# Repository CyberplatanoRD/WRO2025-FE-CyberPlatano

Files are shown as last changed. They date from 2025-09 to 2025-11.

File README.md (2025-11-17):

<h1 align="center">CyberPlátanoRD — WRO</h1>

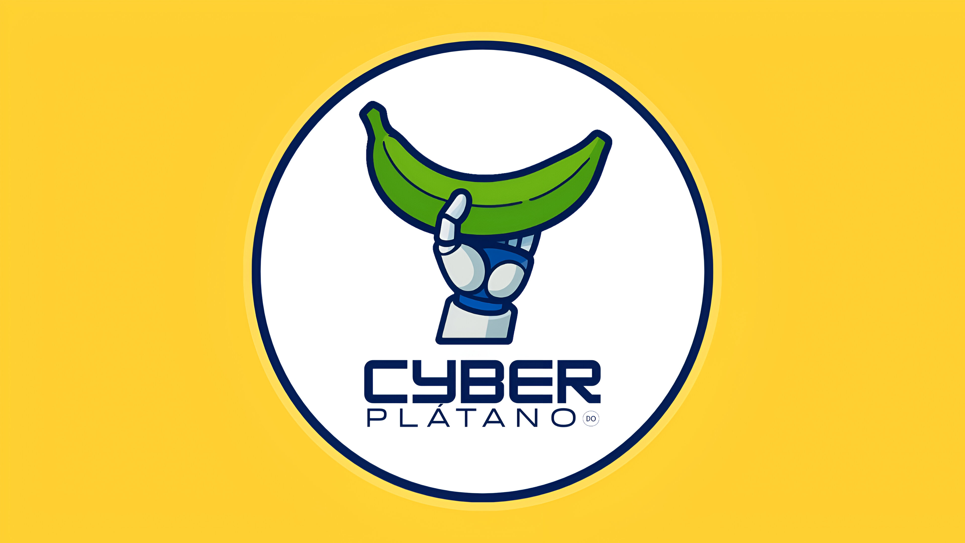
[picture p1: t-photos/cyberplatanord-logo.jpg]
CyberPlátano Logo


> • Pontificia Universidad Católica Madre y Maestra (PUCMM), Dominican Republic • Future Engineers • 2025

---

<p align="center">
  <a href="https://www.youtube.com/@CyberPlatanoWRO">
    
  </a>
  <a href="https://www.instagram.com/pucmm?utm_source=ig_web_button_share_sheet&igsh=ZDNlZDc0MzIxNw==">
    
  </a>
</p>

---

# Engineering Documentation
This repository contains all documentation for the **CyberPlátanoRD** team's robot for the **Future Engineers category - World Robot Olympiad 2025**.  We document the development of our robot, from mechanical and electronic components to programming and simulation.

# Repository Overview

| Folder/File | Description |
|---|---|
| `models` | Files for models used by 3D printers to produce the vehicle elements. |
| `other` | Other essential files. |
| `schemes` | Schematic diagrams of the electromechanical components used in the vehicle and how they connect to each other. |
| `src` | Contains code of control software for all components which were programmed to participate in the competition. |
| `t-photos` | Two photos of the team. |
| `v-photos` | Contains six photos of the vehicle (from every side, from top and bottom). |

# Table of Contents
* [Introduction](#introduction)  
* [About Us](#part-1-about-us)
* [Mobility Management](#part-2-mobility-management)  
* [Power and Sense Management](#part-3-power-and-sense-management)  
* [Obstacle/Open Management](#part-4-obstacleopen-management)

---

# Introduction
This repository documents the journey of Cyberplátano RD, a team representing the Dominican Republic in the World Robot Olympiad (WRO) 2025 – Future Engineers Category, to be held in **Singapore**.

**Our goal** is to design, build, and program an autonomous robot car capable of completing the competition challenges: the Open Challenge and the Obstacle Challenge. The project integrates mechanical design, electronics, and software, combining skills from 3D printing, circuit design, and programming in C++ and Python.

By sharing our process through this repository, **we aim** to provide transparency in our work, create a detailed record of our engineering decisions, and contribute to the global robotics community. Every step, from materials and schematics to testing and results, is documented here.

## Documentation Video

---

# Part 1: About Us

## Our Team 
We are CyberPlátano, representing the Caribbean, Dominican Republic. Part of the PUCMM Robotics Club and guided by our mentor Álvaro Zapata, we are a group of young future engineers. Our club first competed in WRO 2023 in Panamá, and this year we continue our journey, bringing innovation, teamwork, and passion to the international stage in Singapore.

Our team consists of three Mechatronics Engineering students from  "Pontificia Universidad Católica Madre y Maestra (PUCMM)" currently in their third semester. We met during our studies and decided to collaborate as teammates, driven by our shared interest in robotics and innovation. Throughout our academic journey, we have gained valuable experience from our university projects and from the guidance of our professors and peers. This collaboration and learning process have led us to participate together on this international stage.

---

##  Team Members

#### 1. Ivan Saint-Hilaire - Software / Mechanical Eng. ####
| Photo | Role |
|---|---|
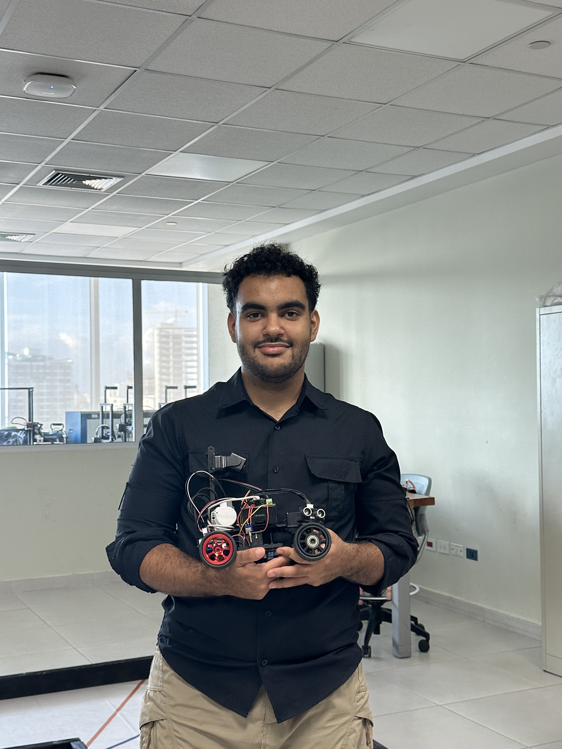
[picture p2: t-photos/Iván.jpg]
|   | Iván is responsible for designing and optimizing the mechanical components of the robot while also developing and integrating the software that controls its functions. His expertise ensures that the robot operates efficiently, accurately, and reliably, bridging the gap between hardware and software.|

#### 2. Brittany Martinez - Team Coordinator and Document Designer  ####
| Photo | Role |
|---|---|
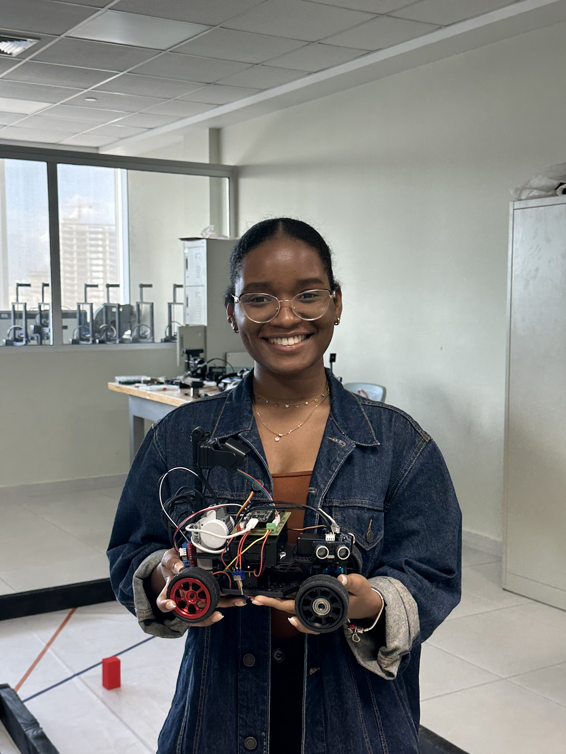
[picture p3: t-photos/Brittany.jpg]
|  | Brittany is responsible for documentation. She has skills in electronics and programming, which allow her to keep the team’s processes well organized. She also ensures that all procedures and systems the team works on are carried out accurately and correctly, maintaining a clear workflow.|

#### 3. Maria Liz Ramos  - Electronics Eng. ####
| Photo | Role |
|---|---|
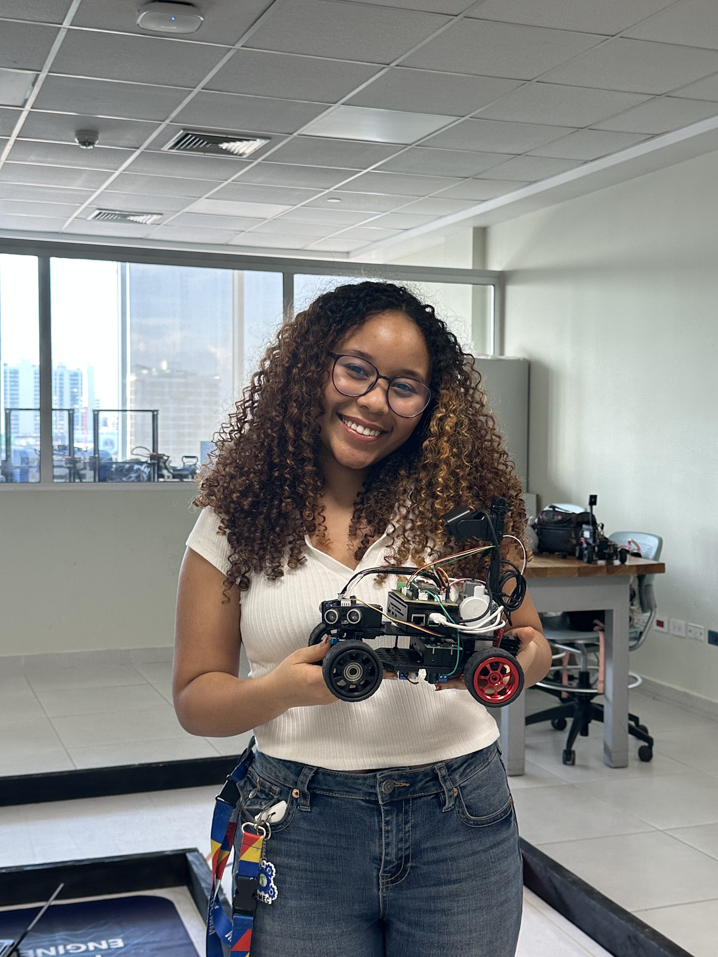
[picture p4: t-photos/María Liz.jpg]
|   | María is responsible for designing, implementing, and maintaining the robot’s electronic systems, ensuring all sensors, circuits, and components function accurately and reliably for optimal performance in the competition.|

#### Alvaro Zapata  - Coach ####
| Photo | Role |
|---|---|
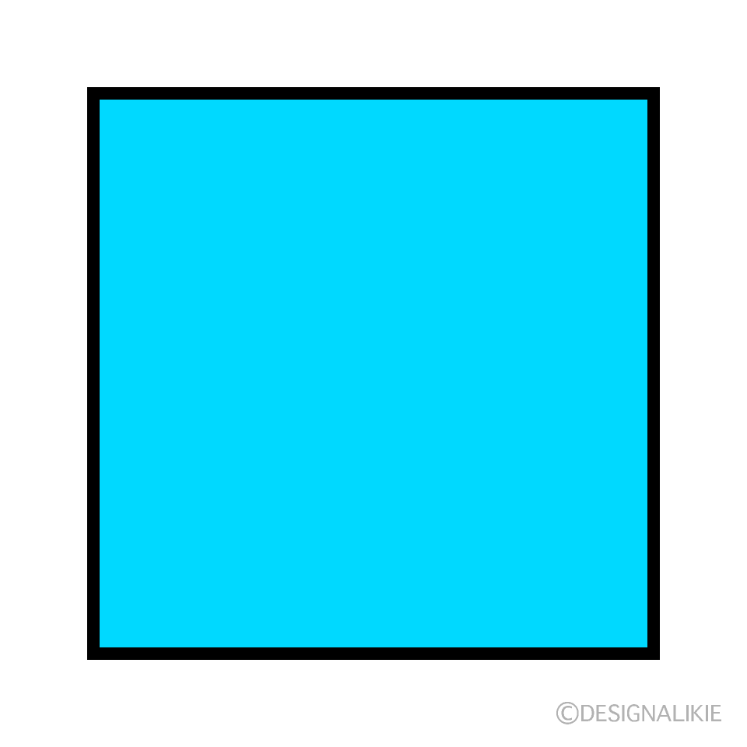
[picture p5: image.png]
|  | Alvaro is a Mechatronics Engineer, he mentors the team, providing technical guidance, strategic advice, and support to ensure the robot performs efficiently and the team works effectively.|

---

##  Work Schedule

This Gantt chart shows the planned timeline for the development of the WRO Future Engineers 2025 robot. It summarizes the main project phases—including design, mechanical build, electronics integration, software development, testing, and final optimization providing a clear view of deadlines and progress for each task.

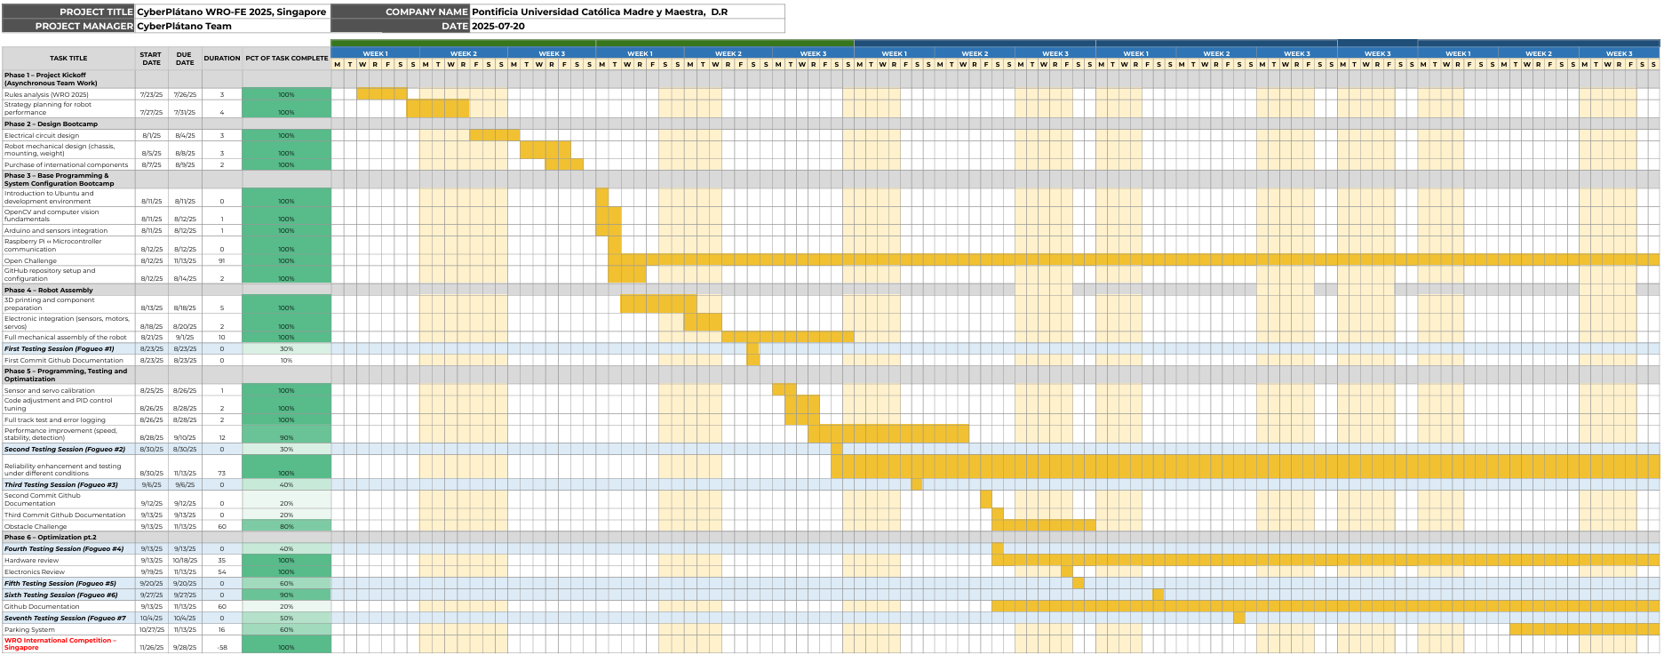
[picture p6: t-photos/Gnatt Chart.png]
Gantt Chart


---

# Part 2: Mobility Management
---
## Robot's Chassis 
Our robot’s chassis has been completely designed and developed from scratch, using Fusion 360 and 3D-printed in black PLA. The design philosophy is centered around modularity, balance, and accessibility, allowing easy modifications, component replacements, and upgrades throughout the development cycle.

We structured our chassis with three essential parts, each designed to provide both strength and modularity to the overall frame:

- **Main Base:** the central foundation that supports the main driving axis, ensuring precise alignment, rigidity, and stability for the entire chassis. 

- **Back Support**: provides mechanical rigidity and structural stability when handling torque or minor impacts. It connects the rear section of the chassis to the upper base and securely holds the drivetrain motor, maintaining alignment under load.

- **Upper Base:** holds the Raspberry Pi 5 and ESP32-CAM circuit, securing them in a stable and elevated position. It also locks the soldered board and supports the ultrasonic sensor mount, ensuring optimal positioning and cable organization.

- **Standoff:** connects the upper base and the main base, maintaining structural spacing and alignment between both layers. It provides rigidity and prevents vibrations from transferring between mechanical and electronic components.

Each element interlocks seamlessly, resulting in a lightweight yet durable frame. Cable management channels were integrated into the design to maintain a clean wiring layout and prevent interference with moving parts. The modular assembly also allows future versions to incorporate sensor mounts or additional mechanical features without redesigning the entire frame.

During the design process, special attention was given to:

- **Weight distribution**, ensuring the center of gravity remains low and centered.

- **Thermal management**, by maintaining airflow under the electronics.

- **Maintenance accessibility**, allowing any component to be removed within minutes.

All the 3D printable models can be found [here](#models).

---
## Robot's Steering System 
---
<p align="justify">
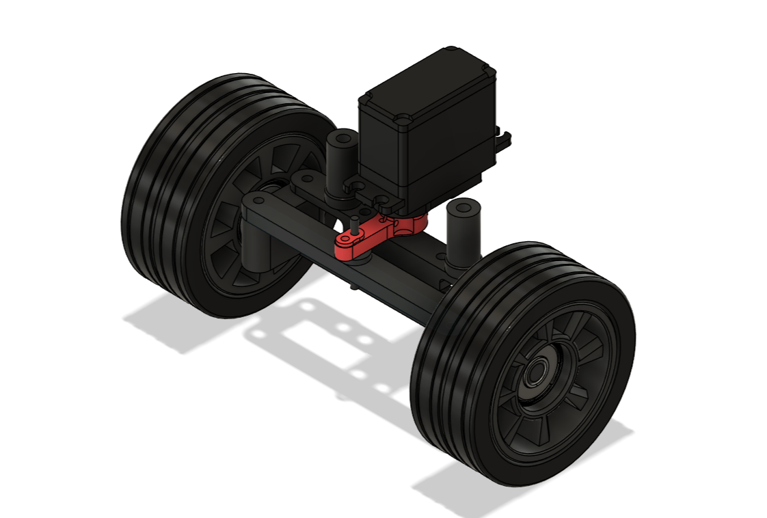
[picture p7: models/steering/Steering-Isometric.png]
  
  Our robot's steering system was designed to provide precise and stable control of forward movement, ensuring the necessary maneuverability across different competition scenarios. We drew inspiration from <em>Ackermann steering system</em>, a configuration that allows a vehicle's front wheels to turn at different angles, enabling them to trace arcs with different radii during a turn. This prevents slipping and improves stability. The entire steering mechanism was developed and modeled in Fusion 360, prioritizing structural integration, modularity, and ease of maintenance. 
</p>

[Click here to view 3D model!](models/steering/steeringSTL.stl)

---
### Steering System Design
---
We took inspiration from a steering design previously developed by our coach, as well as several robotic systems found online. Building upon these references, we carried out an iterative improvement process to address issues related to tolerance, rigidity, and assembly accuracy inherent to 3D-printed components.

In our first prototype, the holes were designed with excessive tolerance, causing loose fits that affected the wheel hubs’ precision and stability. This led to misalignment and unwanted wheel play.

Throughout development, we produced **three main iterations** of the wheel hub design:

1. **First version:** It relied heavily on tight fitting between printed parts, making the design highly sensitive to printer tolerance variations. The wheels were not firmly secured and tended to detach during movement.
2. **Second version:** The fit dependency was reduced, and performance slightly improved; however, the vehicle’s axle and the hub’s axle were designed as separated parts within the same assembly. This made the system mechanically complex and caused lateral play in the wheels. Under repeated stress, the structure eventually fractured.
3. **Final version:** We decided to fully replace the tire rim with a 3D-printed one, which simplified the wheel-to-chassis connection and increased structural rigidity. We also incorporated design inspiration from other teams and opted to use **two 608ZZ bearings** instead of four, which effectively reduced lateral movement without sacrificing rotational smoothness.

Our final steering design combines rigidity, modularity, and precise control while maintaining the simplicity required for quick maintenance and adjustments during the competition.

The steering system consists of the following components:

| No. | Component | Description | Material / Specs |
|:---:|:---|:---|:---|
| 1 | **Under Column** | Lower support structure connecting wheel hubs and servo assembly. | PLA (3D printed), infill 20%, 0.2 mm layer height |
| 2 | **Upper Column** | Upper link supporting the servo and steering mechanism. | PLA, 20% infill, 0.2 mm |
| 3 | **StandOff 1 / 2** | Connect upper and lower columns maintaining alignment. | PLA, 20% infill |
| 4 | **Servo Hitec HS-485B** | Provides steering torque and precision control. | Torque 4.8 kg·cm 6V, 0.16 s/60° |
| 5 | **Bearings 608ZZ** | Enable smooth wheel rotation with minimal friction. | Ø22 mm × 7 mm |
| 6 | **Horn / Servo Arm** | Transmits motion from servo to steering link. | ABS (purchased from Amazon) |
| 7 | **Steering Link (Tie Rod)** | Connects both wheel hubs ensuring synchronized turning. | PLA, 30% infill |
| 8 | **Wheel Hubs** | Support the wheels and allow rotation through bearings. | PLA, 20% infill |
| 9 | **Steering Arm** | Intermediate printed lever that connects the servo horn to the steering link, transmitting motion. | PLA, 20% infill |

###  Steering Subassembly
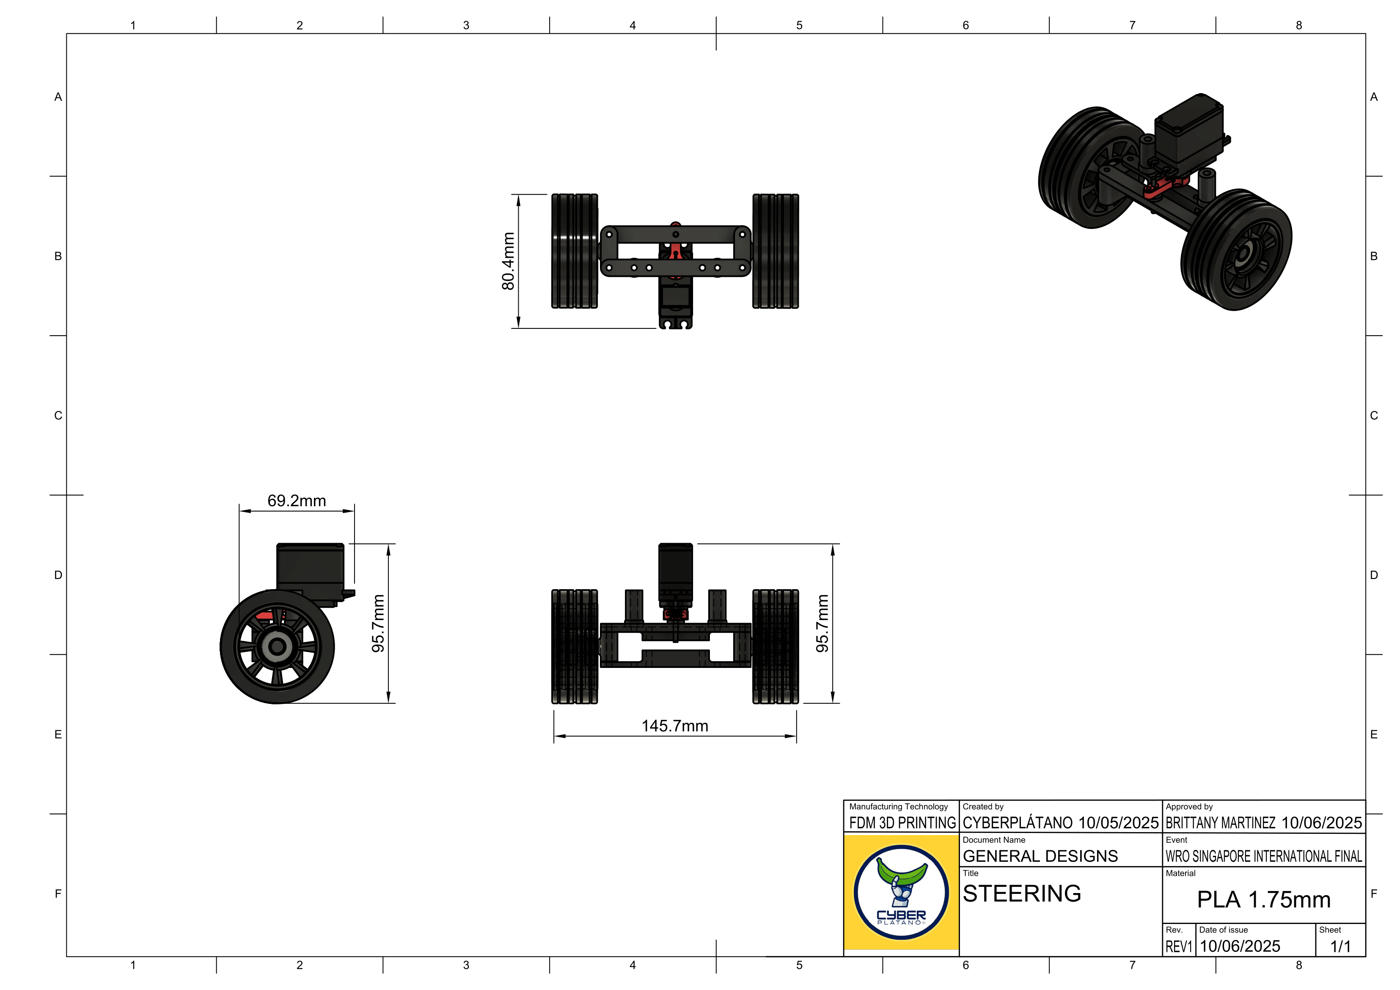
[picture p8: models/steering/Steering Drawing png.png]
Steering Drawing


### 1. Under and Upper Columns 
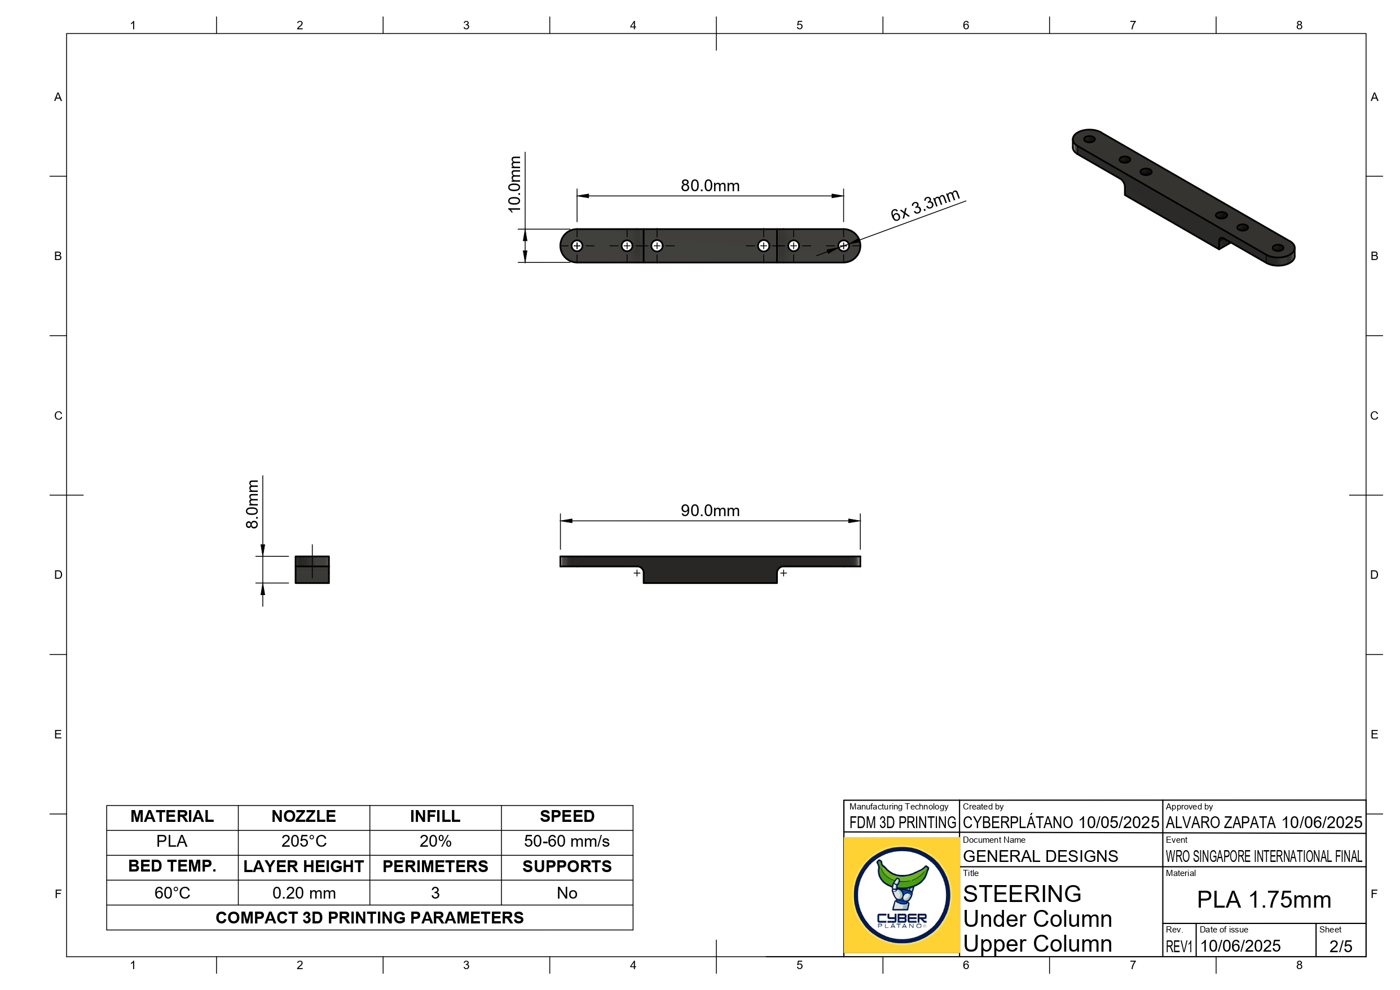
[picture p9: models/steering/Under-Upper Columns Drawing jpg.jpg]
Under-Upper Columns Drawing


### 2. Stands Off 
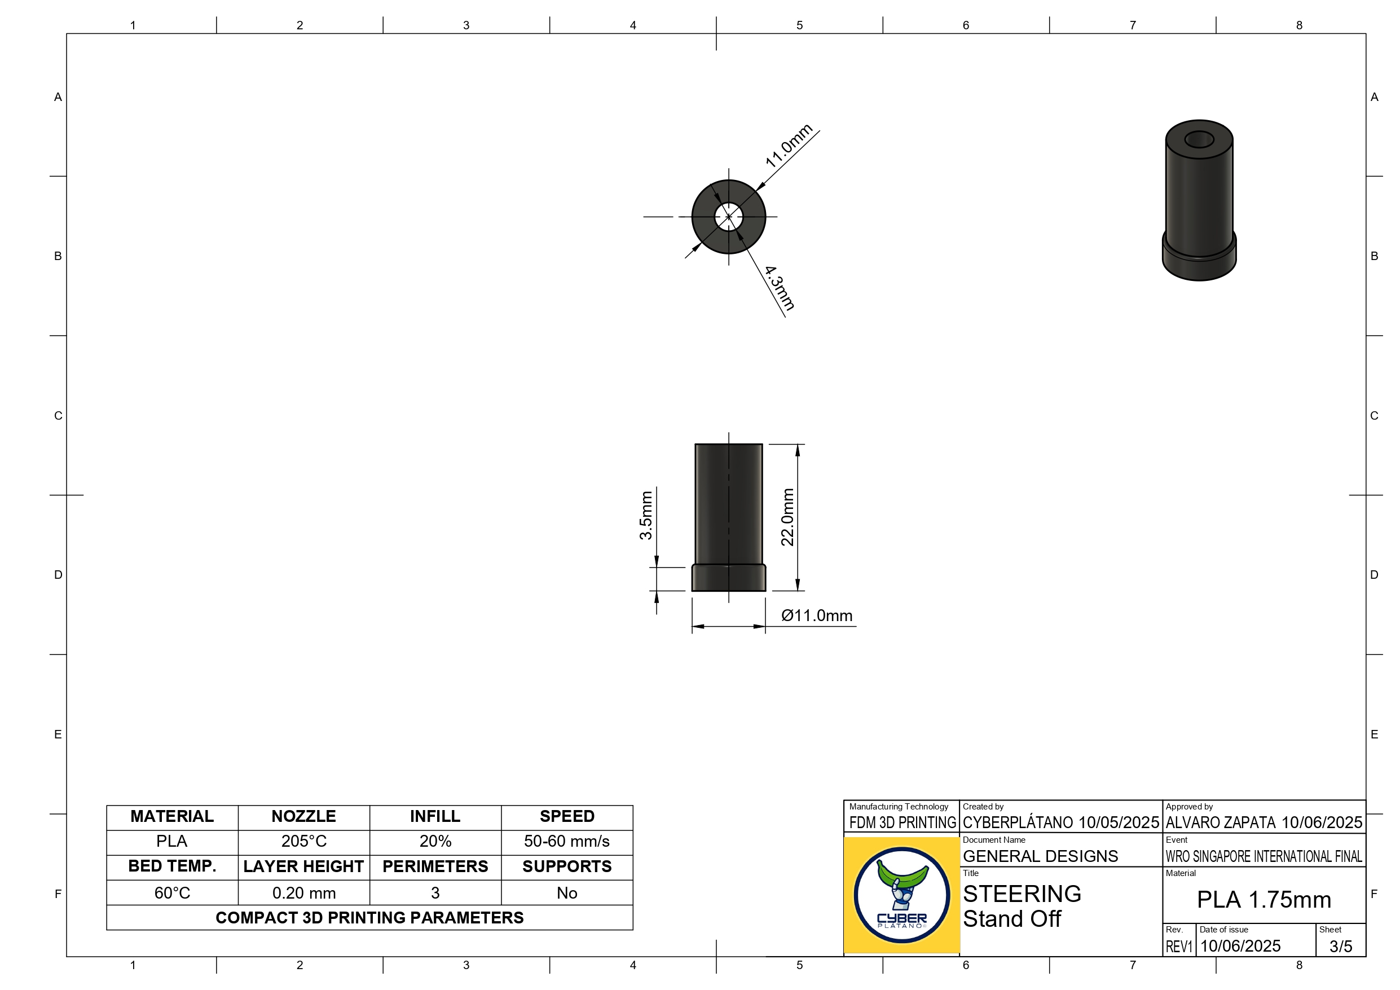
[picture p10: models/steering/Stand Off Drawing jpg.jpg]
Stand Off Drawing


### 3. Steering Arm
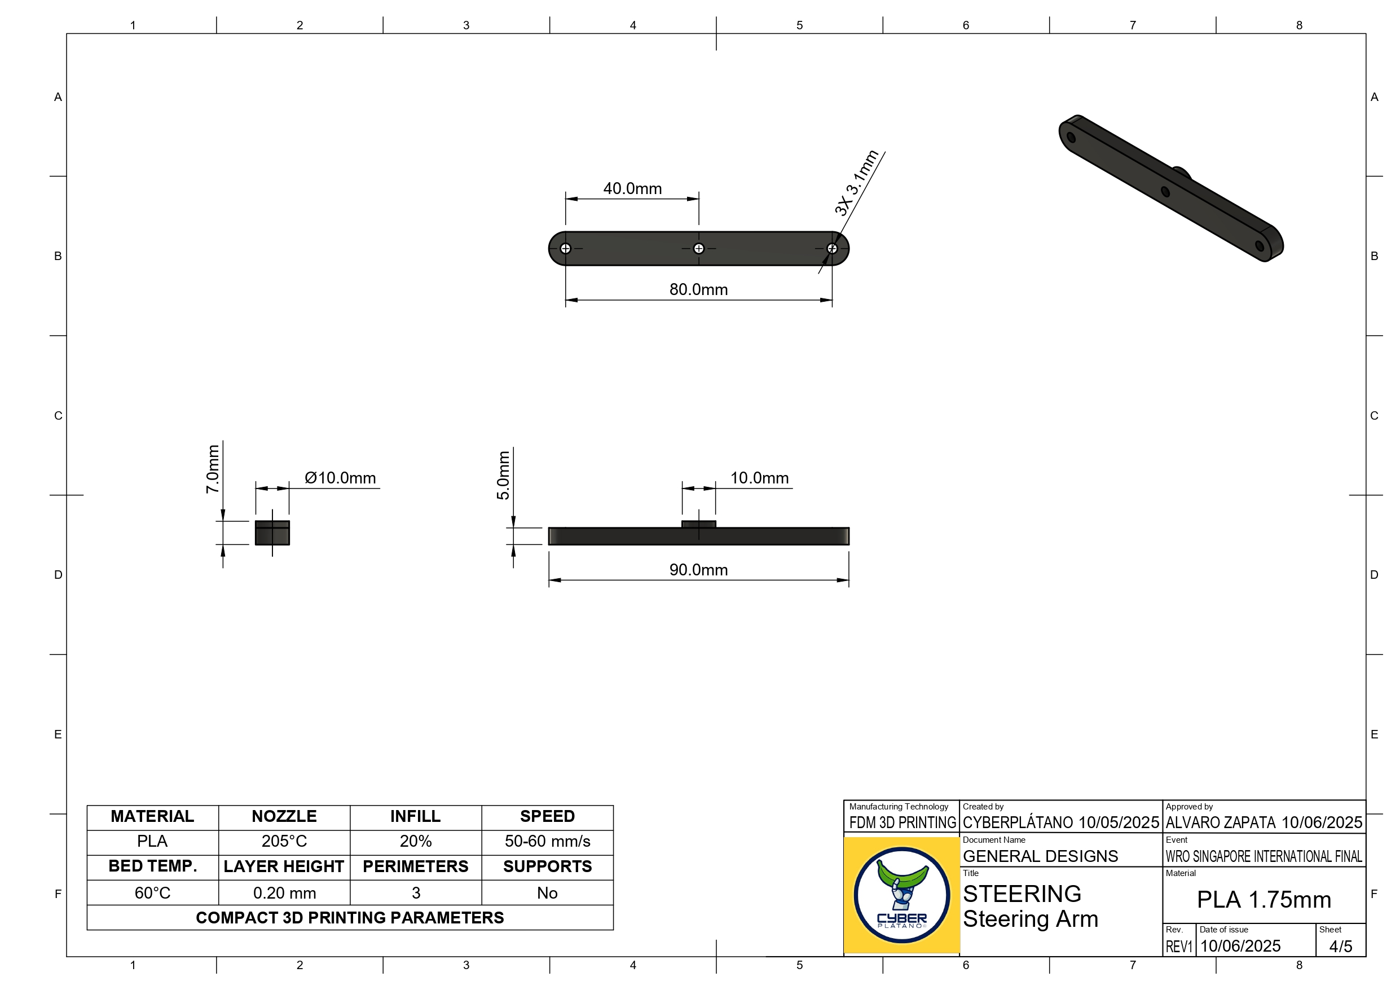
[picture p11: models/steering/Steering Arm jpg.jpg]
Steering Arm Drawing


### 4. Frontal Rims 
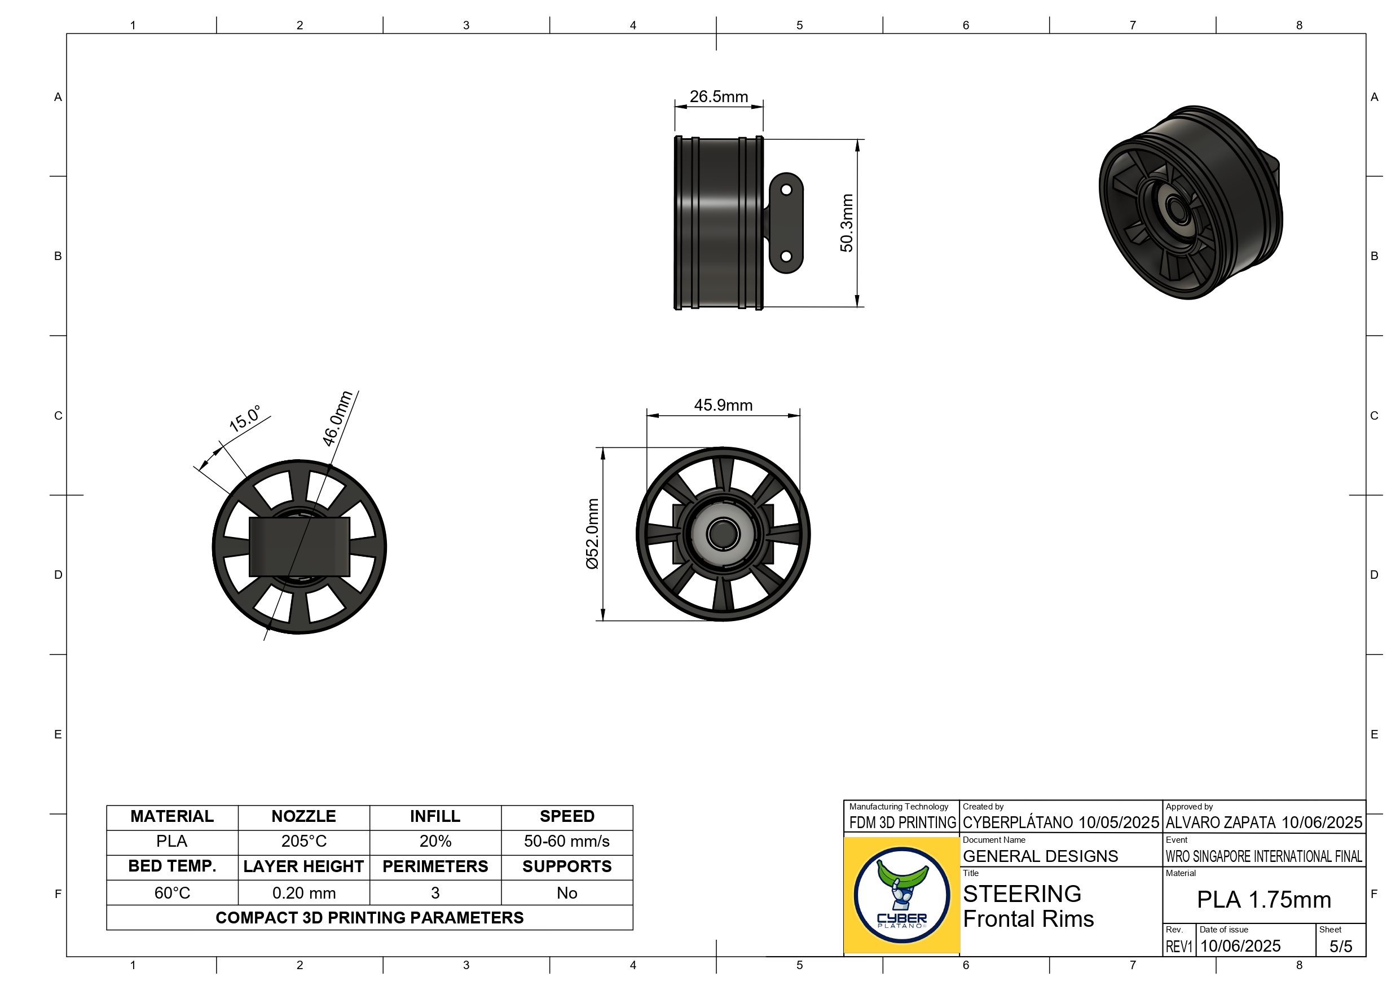
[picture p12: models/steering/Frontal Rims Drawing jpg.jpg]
Frontal Rims Drawing


---
### Our Key Steering Component: HS-485HB Servo Motor
---
Our primary steering component—the Hitec HS-485HB servo motor was initially chosen because it was the unit available to us at the time, extensive testing quickly proved it to be a reliable and well-suited choice for our steering system. Over more than three months of continuous use, the HS-485HB has demonstrated excellent consistency, durability, and torque stability, even under repetitive steering cycles and high-load maneuvers typical of competition environments. Its Karbonite gear train, known for increased wear resistance, has provided smooth motion transfer without backlash, and its response time has been fast enough to ensure accurate directional control on the field. What began as a practical selection evolved into a confident engineering decision, reinforced by the servo’s performance, structural robustness, and zero failure rate throughout our development process.

<table>
  <tr>
    <td align="center" width="450">
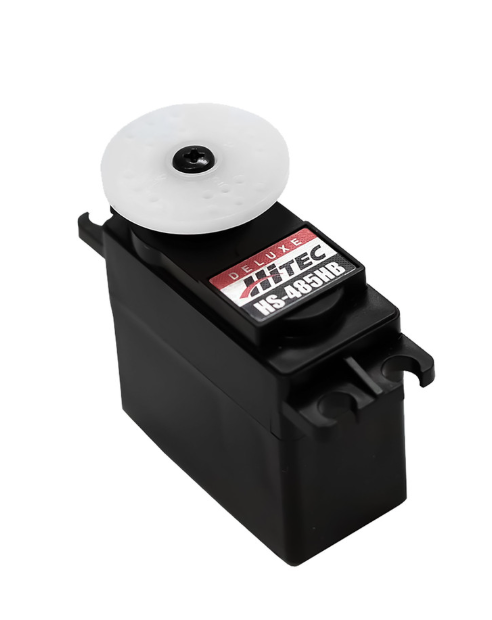
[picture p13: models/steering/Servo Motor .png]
      
      <br>
      <b>HS-485HB Servo Motor</b>
    </td>
    <td>

| **Parameter** | **Specification** |
|---|---|
| Servo type | Standard, limited rotation (±60°) |
| Operating voltage | 4.8 V – 6.0 V |
| Torque | 4.8 kg·cm @ 4.8 V / 6.0 kg·cm @ 6.0 V |
| Speed | 0.22 s/60° @ 4.8 V / 0.18 s/60° @ 6.0 V |
| Gear material | Karbonite (high wear resistance) |
| Bearing type | Dual ball bearings |
| Dimensions | 39.8 × 19.8 × 38.0 mm |
| Weight | 45 g |
| Output spline type | 24T (Hitec) |
| PWM signal range | 900–2100 µs (typical) |
| Operating current | ~160–200 mA (under moderate load) |
| Stall current | Up to ~1.2 A (approx., depending on load) |
| Case material | Reinforced plastic |
| Connector | Futaba-type (3-pin) |

  </td>
  </tr>
</table>

---
### Bill of Materials (BOM)
---
| **Component** | **Description** | **Qty** | **Unit Price (USD)** |
|---|---|---|---|
| [Raspberry Pi 5](https://a.co/d/0I2nEqT) | Main computer used for high-level processing and running computer vision algorithms. | 1 | $98.00 |
| [ESP32](https://a.co/d/hiSPSgg) | Microcontroller responsible for real-time control of motors and sensors, communicating with the main processor. | 1 | $10.00 |
| [Motor Lego NXT](https://ebay.us/m/x9oEc6) | DC motor with encoder used for driving the wheels, providing precise speed and position feedback. | 1 | $7.00 |
| [NXT Lego Cable](https://ebay.us/m/tDWV4P) | Connects NXT motors and sensors to the control electronics. | 1 | $1.50 |
| [65mm Wheels](https://es.aliexpress.com/item/1005008744796805.html) | Provide traction and mobility to the robot. | 4 | $5.00 |
| [H-Bridge (L298N)](https://a.co/d/6sx6nvQ) | Motor driver that allows bidirectional control of the DC motors, enabling forward and backward movement. | 1 | $2.50 |
| [Creality Nebula Camera](https://a.co/d/1rddk0F) | Captures real-time video feed for visual processing, compatible with Raspberry Pi and AI-based image recognition. | 1 | $29.00 |
| [Servo Motor HS-485HB](https://a.co/d/8K9dx9H) | Controls steering (front axle movement) or small actuations requiring angular precision. | 1 | $19.00 |
| [Servo Motor Horn](https://a.co/d/hKtnZTU) | Mechanical arm attachment for the servo motor, transmits angular motion to the steering mechanism. | 1 | $9.00 |
| [Ultrasonic Sensor (HC-SR04)](https://a.co/d/gGVXDkd) | Measures distance to nearby objects for obstacle detection and wall avoidance. | 3 | $4.50 each |
| [MPU9250](https://a.co/d/abgbahF) | Inertial Measurement Unit (IMU) that provides accelerometer, gyroscope, and magnetometer data for orientation and navigation. | 1 | $17.00 |
| [Switch SPST 6A](https://a.co/d/7QAXuRy) | Main power switch to safely turn the robot ON/OFF. | 1 | $0.50 |
| [Push Button](https://a.co/d/fHT8FXe) | Used as a start/stop input for robot operation. | 1 | $1.50 |
| Lego Motor Shaft | Mechanical part that transfers torque from the motor to the wheels/axle. | 1 | $0.10 |
| [Dual Power Supply (DC-DC Boost)](https://es.aliexpress.com/item/1005007460824944.html) | Dual-output voltage regulator that steps up DC input to supply stable voltage levels to different modules. | 1 | $4.97 |
| [UPS Power Supply/Converter](https://es.aliexpress.com/item/1005005195434497.html) | Uninterruptible power supply module that maintains power delivery during voltage drops or disconnections. | 1 | $1.40 |
| [Bearings 608zz](https://a.co/d/b21FcTB) | Ball bearings used to reduce friction and support smooth wheel or axle rotation. | 2 | $0.20 |
| [Buck Converter XL4015](https://a.co/d/3TFsw20) | Step-down voltage regulator providing a stable 5V or 12V output for the control electronics. | 1 | $0.98 |
| [PLA Filament (Polylactic Acid)](https://a.co/d/bzdKSjG) | Material used for 3D printing the chassis and custom parts of the robot due to its light weight and ease of printing. | 1 | $25.00 |
| **Total Estimated Cost** |  |  | **$239.85** |

# Part 3: Power and Sense Management
---
This report presents the design, development, and integration of the electrical system implemented in the autonomous vehicle built for the WRO Future Engineers 2025 competition.

The main objective of the electrical subsystem was to provide a **reliable architecture for the robot’s power supply, sensing, processing, and actuation, ensuring stability, safety, and compatibility** with the challenge requirements, where the track changes dynamically in each round.

The system is based on an **ESP32 microcontroller**, responsible for managing the **ultrasonic sensors**, the **Creality Nebula Camera** for color recognition, and motor control. Power is supplied using 18650 lithium batteries, step-down regulators, a dual power source, and a custom PCB design to ensure proper power distribution and minimize interference caused by the motors.

Throughout the development process, tests were conducted on continuity, current consumption, sensor calibration, and digital communication validation. The main challenges included stabilizing the Raspberry Pi 5 power supply, mitigating electrical noise from the motors, dealing with the limited number of available pins, and unstable color readings, which led to several iterations in wiring, pin assignment, and signal filtering.

The results demonstrate that the electrical system met the minimum requirements for functional operation, enabling successful integration with the mechanical and control systems. Finally, potential improvements were identified, such as the implementation of encoders, sensor filtering optimization, and PCB refinement for future versions.

## Schematics
> Diagrams and PCB Layout files available in [schemes/](schemes/).

### Diagram - Preview
[View full PDF](./schemes/WRO_Generalsquematic.pdf)

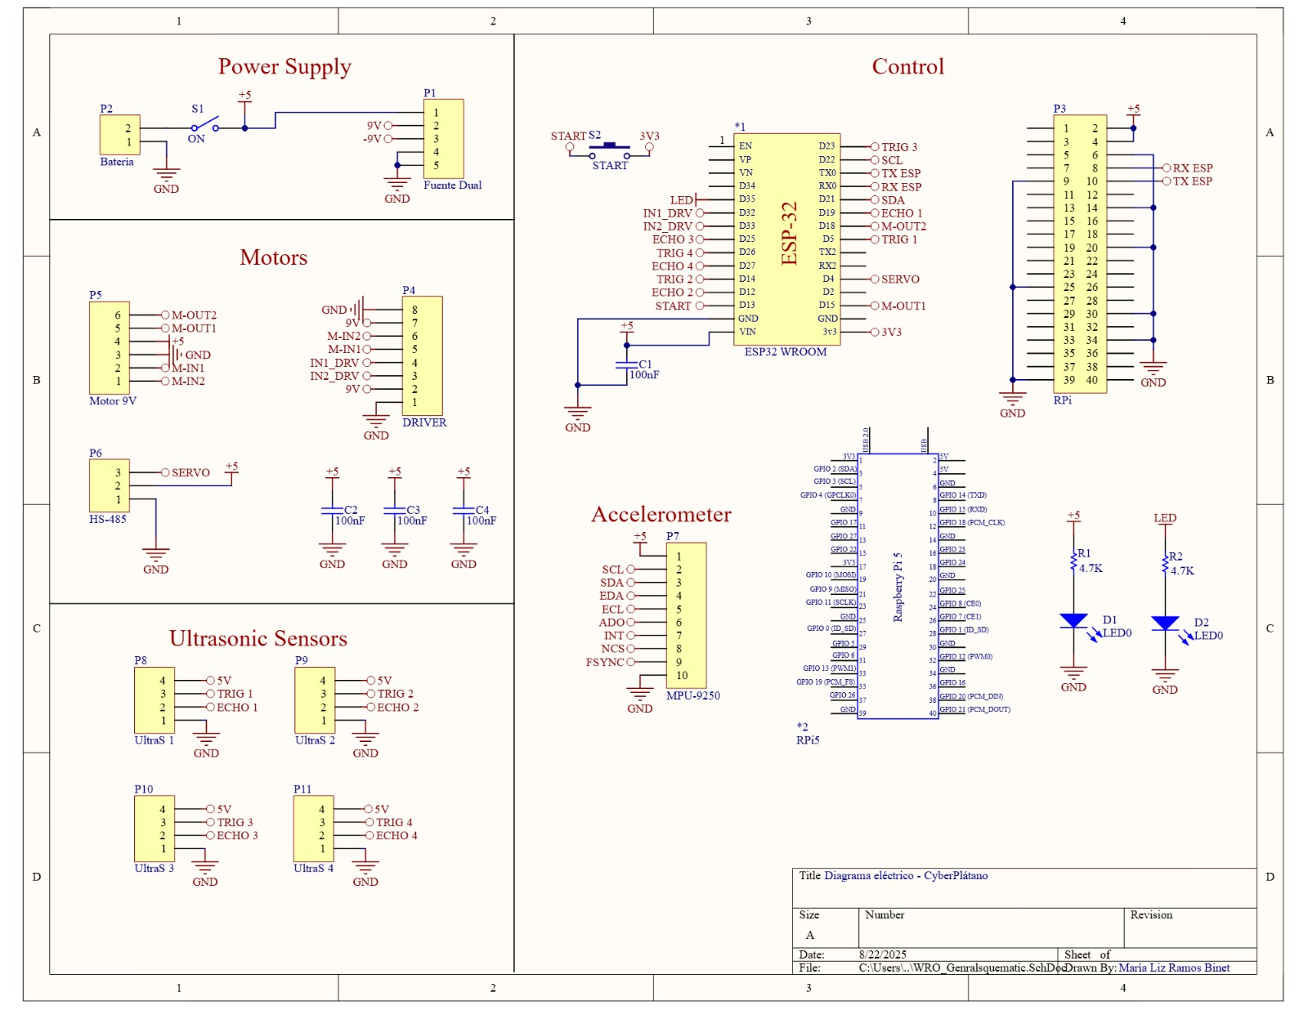
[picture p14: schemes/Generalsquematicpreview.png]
Schematic Preview


### PCB layout - Preview
[View full PCB Layout](./schemes/WRO_Generalpcblayout.pdf)

# Part 4: Obstacle/Open Management
> CPP and Python codes files available in [src/](src/).

### Open challenge - Preview

Below is a short preview of the control logic used in our Open Challenge robot.  

The full version is available here  [`src/open_challengev2.ino`](./src/open_challengev2.ino)

```cpp
#include <Wire.h>
#include <MPU9250_asukiaaa.h>
#include <ESP32Servo.h>

MPU9250_asukiaaa mySensor;
Servo servoMotor;

// Basic yaw control variables
float yaw = 0.0;
float gyroZ_offset = 0.0;

void setup() {
  Serial.begin(115200);
  Wire.begin();
  mySensor.setWire(&Wire);
  mySensor.beginGyro();
  servoMotor.attach(18);
}

void loop() {
  mySensor.gyroUpdate();
  yaw += (mySensor.gyroZ() - gyroZ_offset) * 0.01;
  servoMotor.write(map((int)yaw % 360, 0, 360, 50, 130));
}

// ...rest of preview code...

```
---

### Obstacle challenge
---

## Testing
The **"fogueos"** are an internal dynamic organized by the teams from PUCMM (Pontificia Universidad Católica Madre y Maestra), where participants from WRO Dominican Republic take part in friendly mini competitions.

The main goal is to test the robots under competition-like conditions, evaluate team performance, and share knowledge and improvements among teams.

Throughout this process, our team participated in several fogueos to enhance the robot’s precision, stability, and overall performance:

### "1st fogueo"
### "2nd fogueo"
### "3rd fogueo"
### "4th fogueo"
### "5th fogueo"
### "6th fogueo"
### "7th fogueo"
---

## Instructions

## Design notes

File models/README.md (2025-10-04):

# Models

This folder contains the 3D models and related files for the CyberplátanoRD robot project for WRO 2025.

## Files included

- 3D CAD files (e.g., `.stl`, `.step`, `.obj`) for robot components.
- Assembly models showing how the robot parts fit together.
- Any additional reference files used for simulation or design.

## Notes

- Models can be opened with software such as:
  - Fusion 360
  - SolidWorks
  - Blender
  - Webots (for simulation)
- Make sure to check file versions; some parts may have multiple iterations.

## How to use 

1. Open the CAD or simulation software of your choice.
2. Import the 3D files from this folder.
3. Follow the assembly references to reconstruct the robot.
4. Use the models in simulations, presentations, or for 3D printing.

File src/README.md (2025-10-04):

# Source Code

This folder contains the source code for the Open Challenge and Obstacle Challenge robot of the CyberPlátanoRD team for WRO 2025.

## Files included

- `open_challengev2.ino` – Main Arduino sketch for the robot.
  - Handles motor control, yaw adjustment, servo steering, and ultrasonic sensors.
  - Implements corner detection logic and motor stop after a number of rotations.

## Notes

- The code is designed for ESP32 with MPU9250 sensor, servo motor, L298N driver, and ultrasonic sensors.
- Calibration of the gyroscope is performed in the `setup()` function.
- The main loop integrates sensor readings and controls motors and servo based on yaw and ultrasonic distances.

## How to use

1. Open the `.ino` file in Arduino IDE or VS Code with PlatformIO.
2. Make sure all required libraries are installed:
   - `MPU9250_asukiaaa`
   - `ESP32Servo`
3. Connect the ESP32 and upload the sketch.
4. Adjust pins if needed for your hardware setup.

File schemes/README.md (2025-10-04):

# Schematics

This folder contains the schematics and layout files for our WRO 2025 robot project.

## Files included

- `WRO_Generalsquematic.pdf` – Full schematic of the robot, showing all circuits and connections.
- `Generalsquematicpreview.png` – Preview image of the schematic for quick reference.

## Notes

- The PDF file contains detailed information on motor control, sensors, Raspberry Pi 5 and the ESP32-CAM connections.
- The preview image is used in the main README for a quick visual reference.

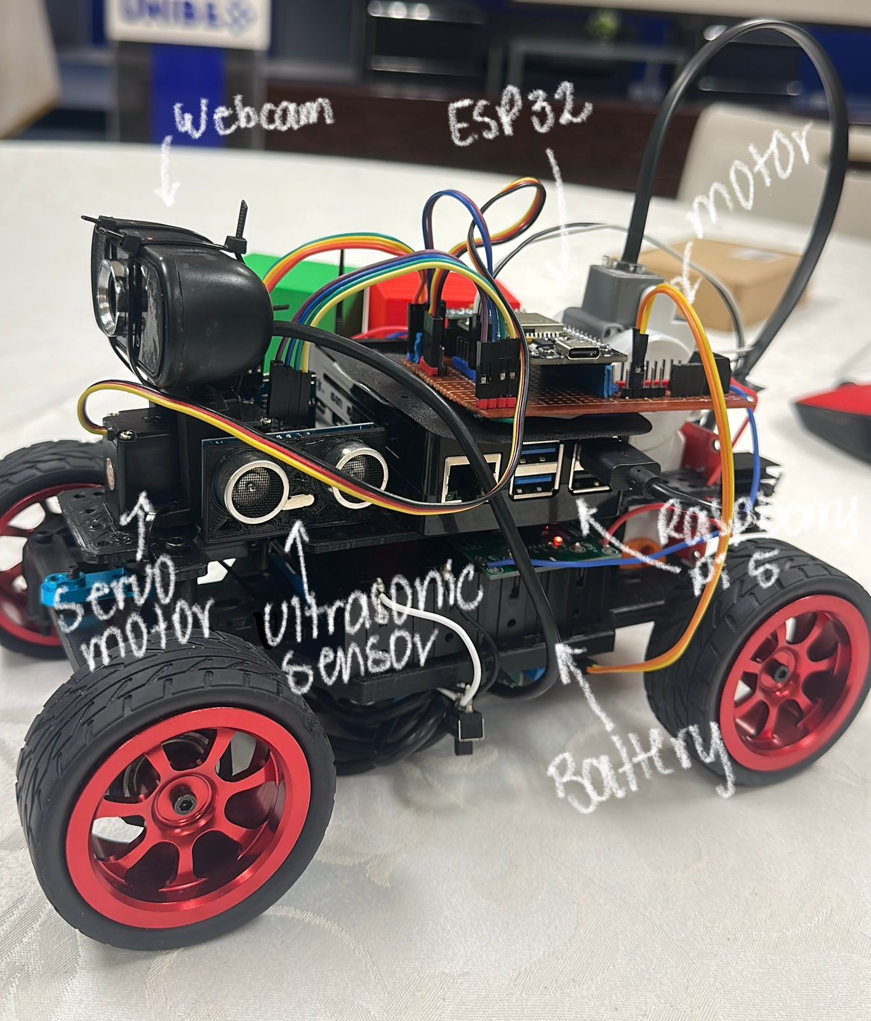
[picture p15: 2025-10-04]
other/Isometric.jpeg

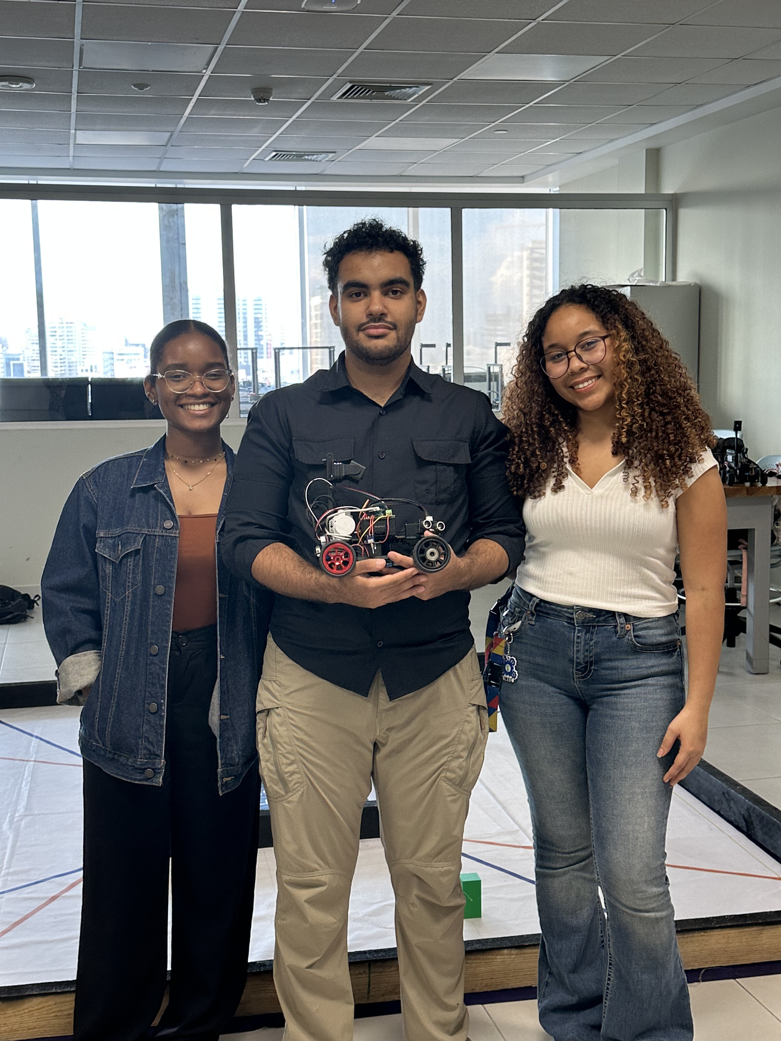
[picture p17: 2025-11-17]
t-photos/Team.jpg

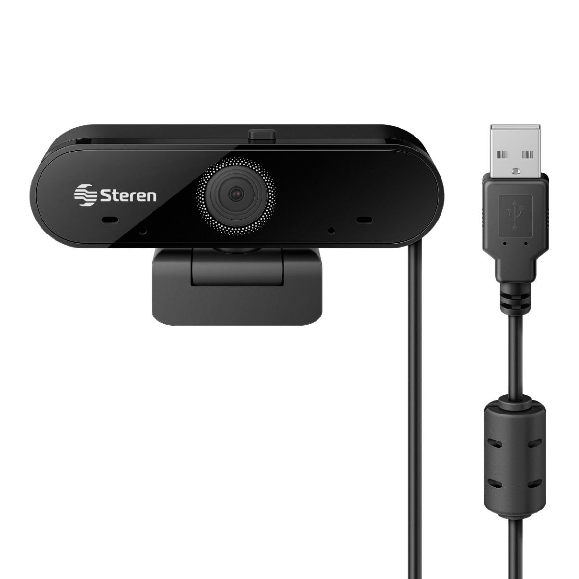
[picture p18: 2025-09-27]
other/webcam.png

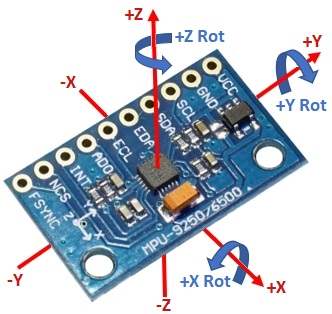
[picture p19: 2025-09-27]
other/IMU.png

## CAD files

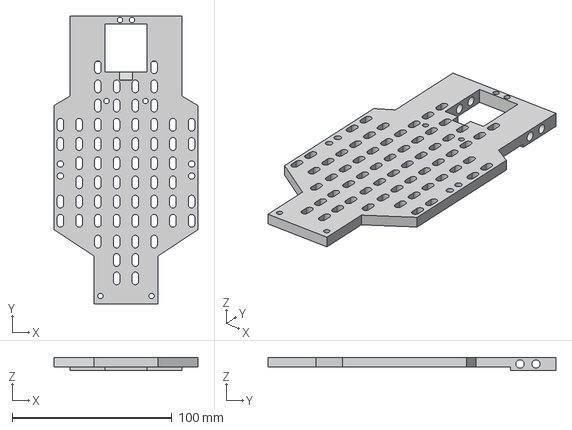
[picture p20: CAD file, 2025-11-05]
models/chassis/main_base/mainBase.step
90.0 x 180.0 x 8.00 mm

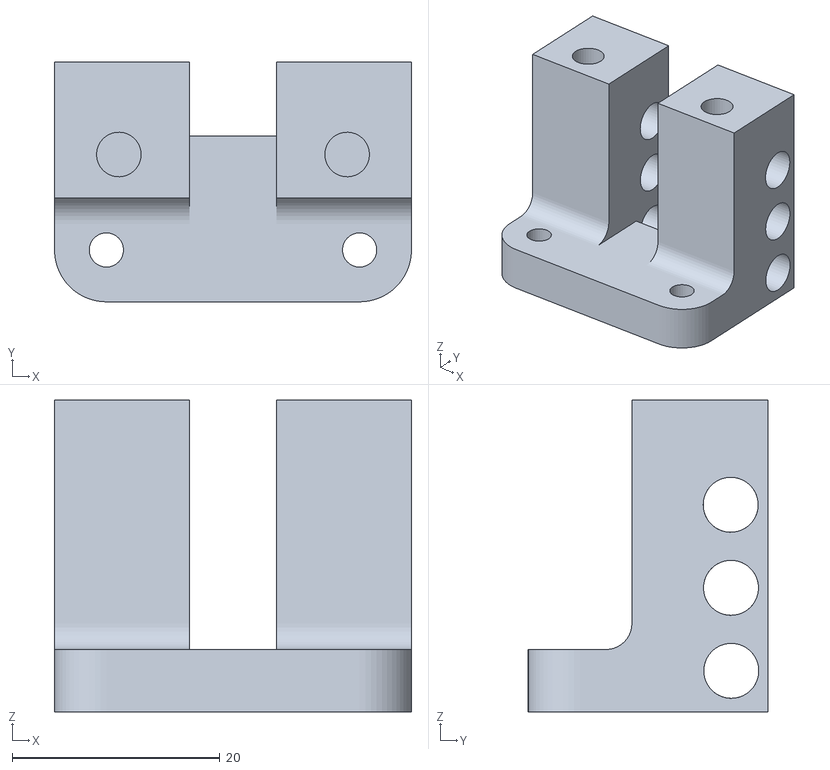
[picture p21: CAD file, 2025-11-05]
models/chassis/back_support/backSupportSTL.stl
34.4 x 23.1 x 30.0

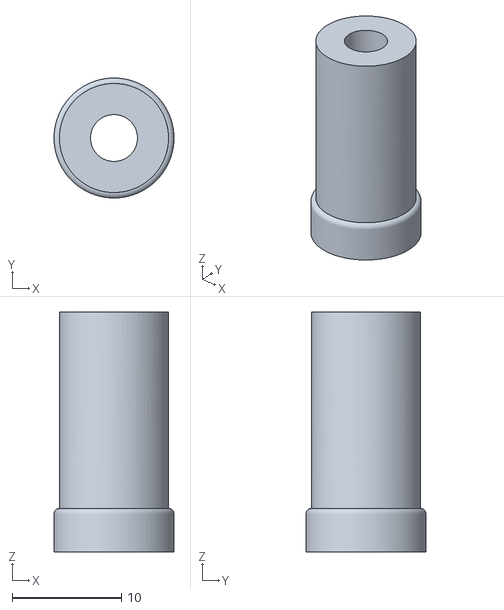
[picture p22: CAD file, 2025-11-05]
models/chassis/stand_off/standOffSTL.stl
11.0 x 11.0 x 22.0

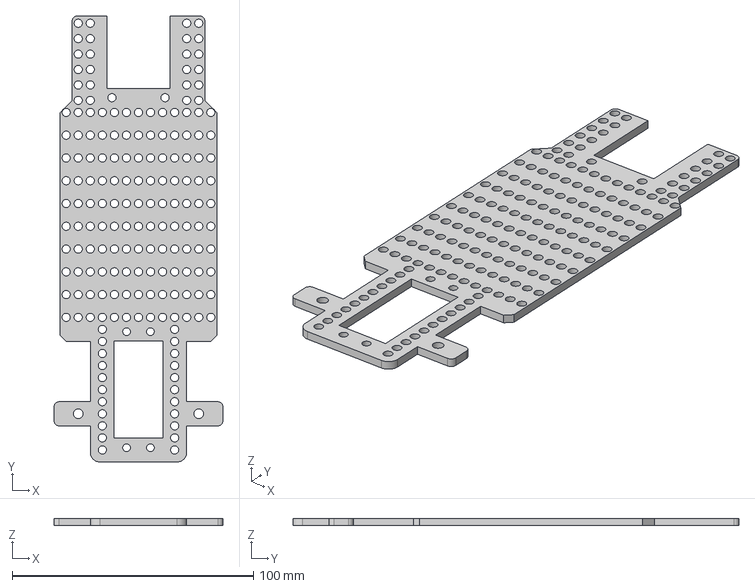
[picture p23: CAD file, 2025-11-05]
models/chassis/upper_Base/upperBase.step
70.0 x 185.0 x 3.00 mm

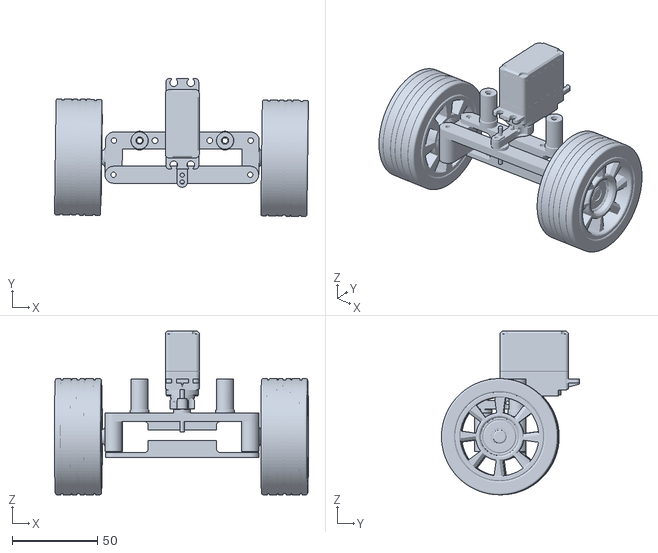
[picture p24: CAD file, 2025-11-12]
models/steering/steeringSTL.stl
148.6 x 80.8 x 95.7

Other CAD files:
models/firsyAssembly.stl
models/chassis/main_base/mainBaseSTL.stl
models/chassis/back_support/backSupport.step
models/chassis/stand_off/standOff.step
models/chassis/upper_Base/upperBaseSTL.stl

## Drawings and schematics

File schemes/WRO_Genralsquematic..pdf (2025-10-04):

## D18 D19 D21

# VIN GND D13 D12 D14 D27 D26 D25 D33 D32 D35 D34 VNVPEN

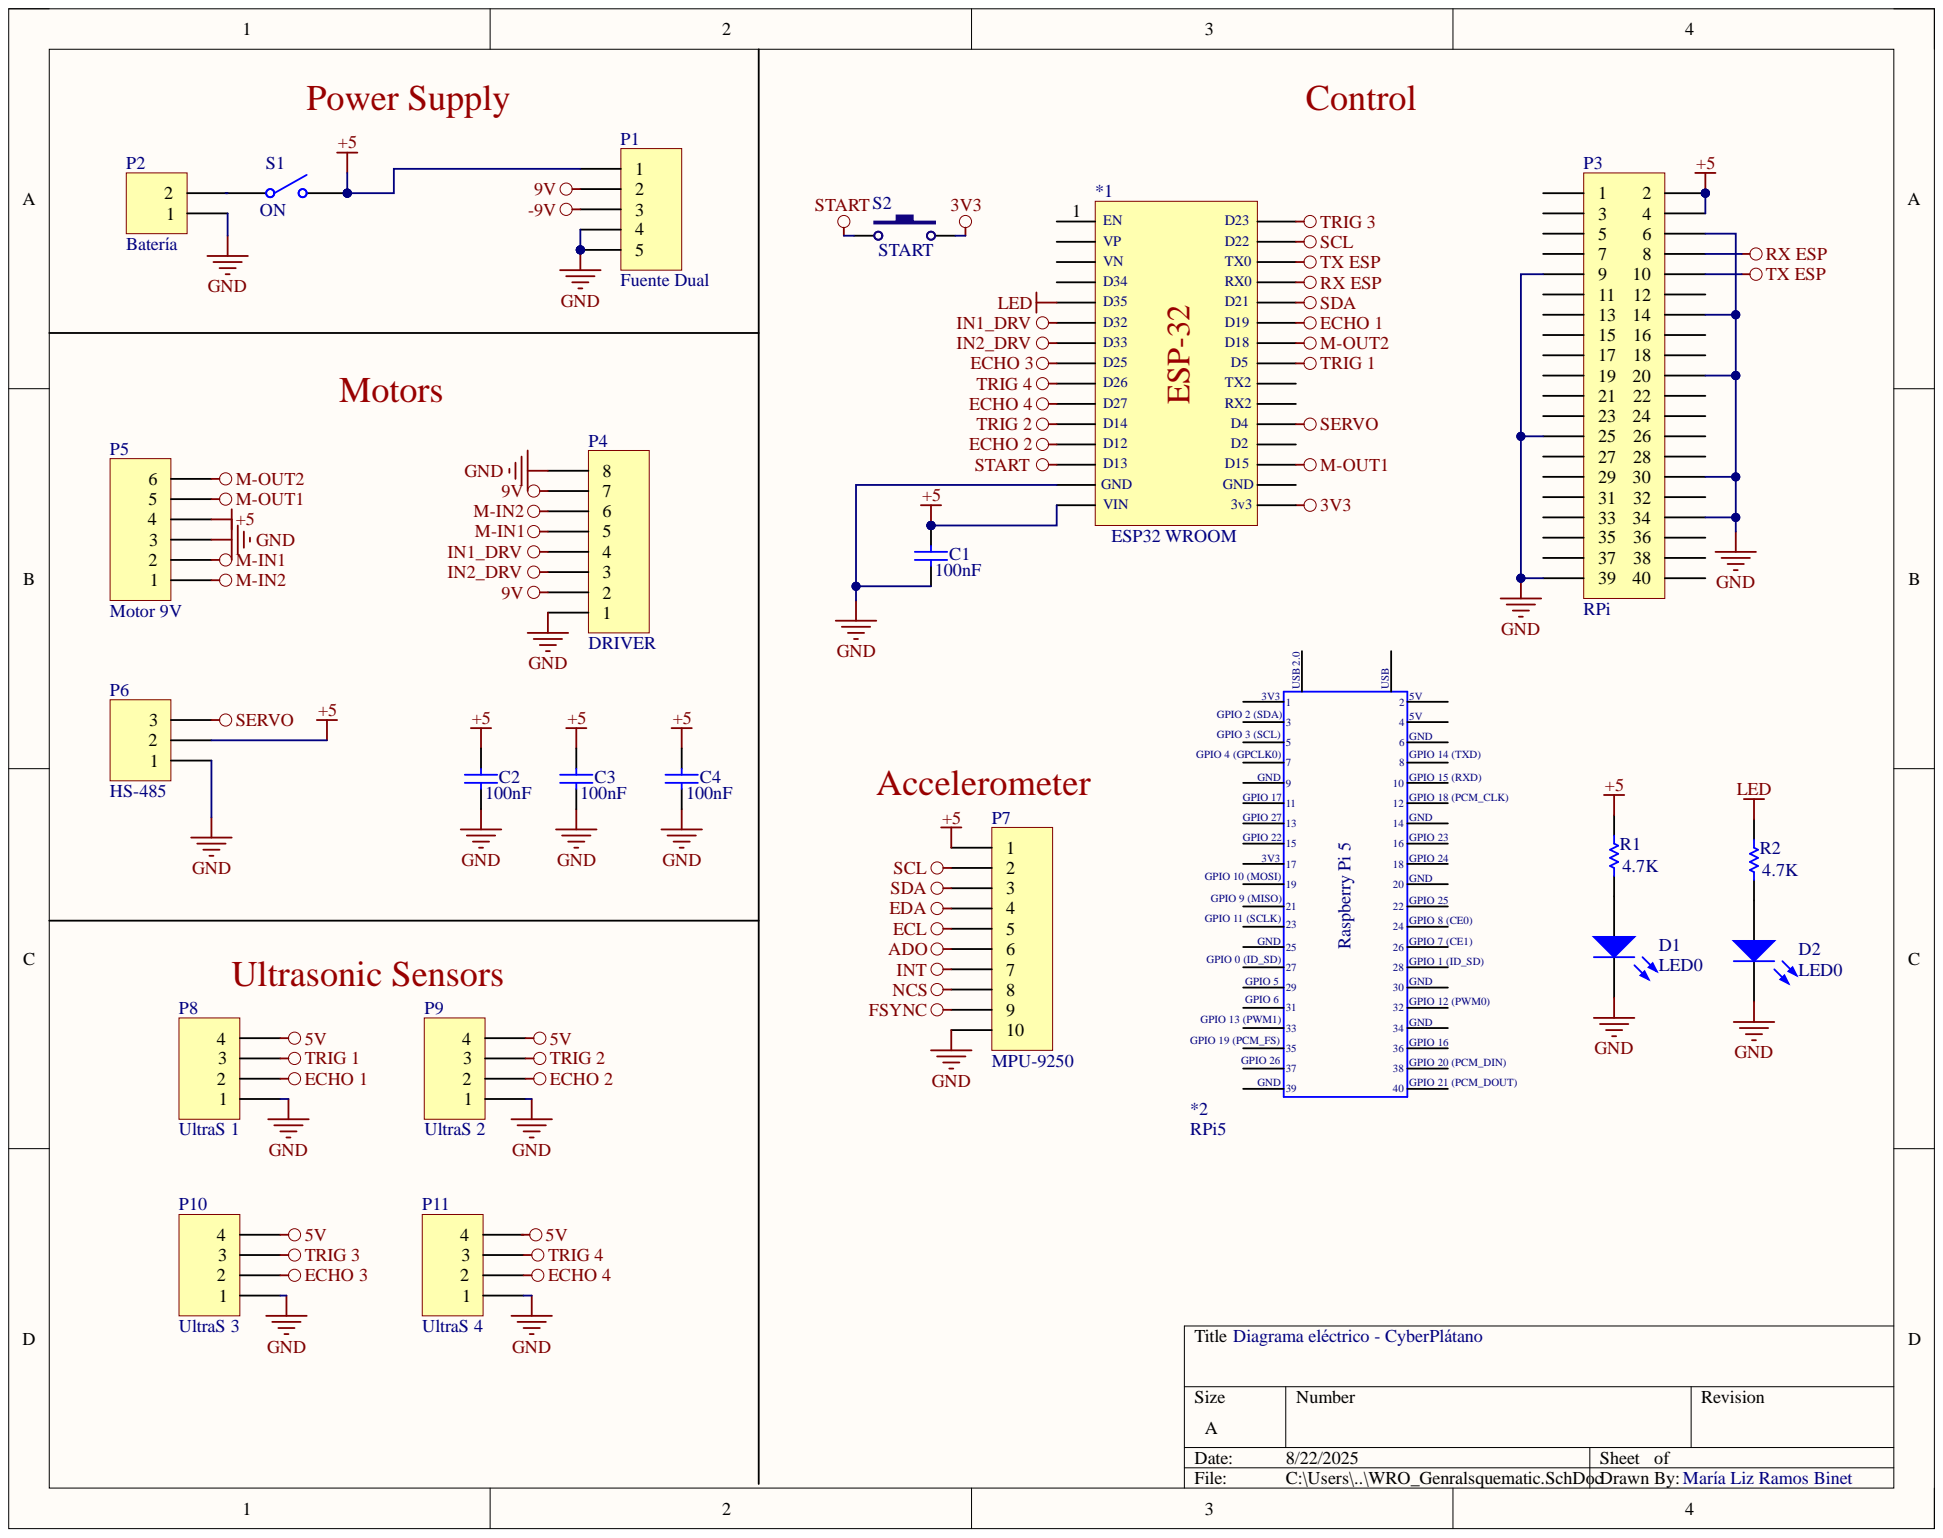
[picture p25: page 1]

SCL SDA EDA ECL ADO

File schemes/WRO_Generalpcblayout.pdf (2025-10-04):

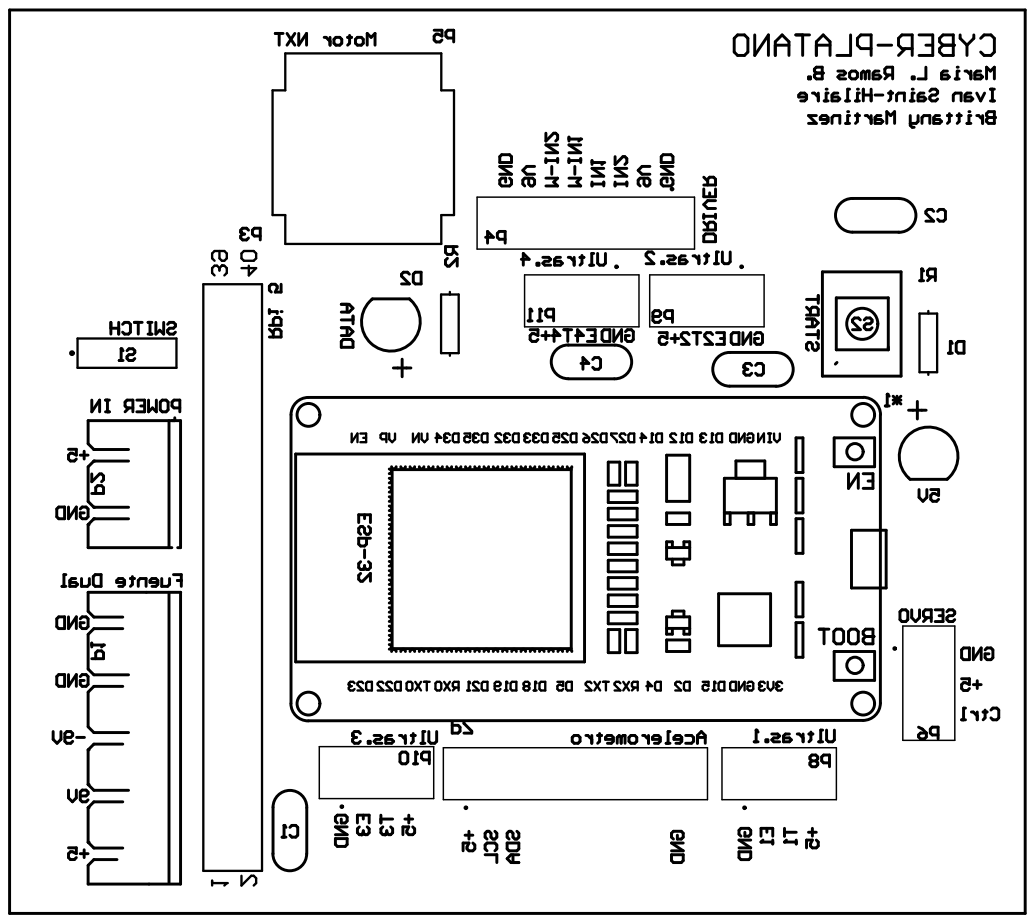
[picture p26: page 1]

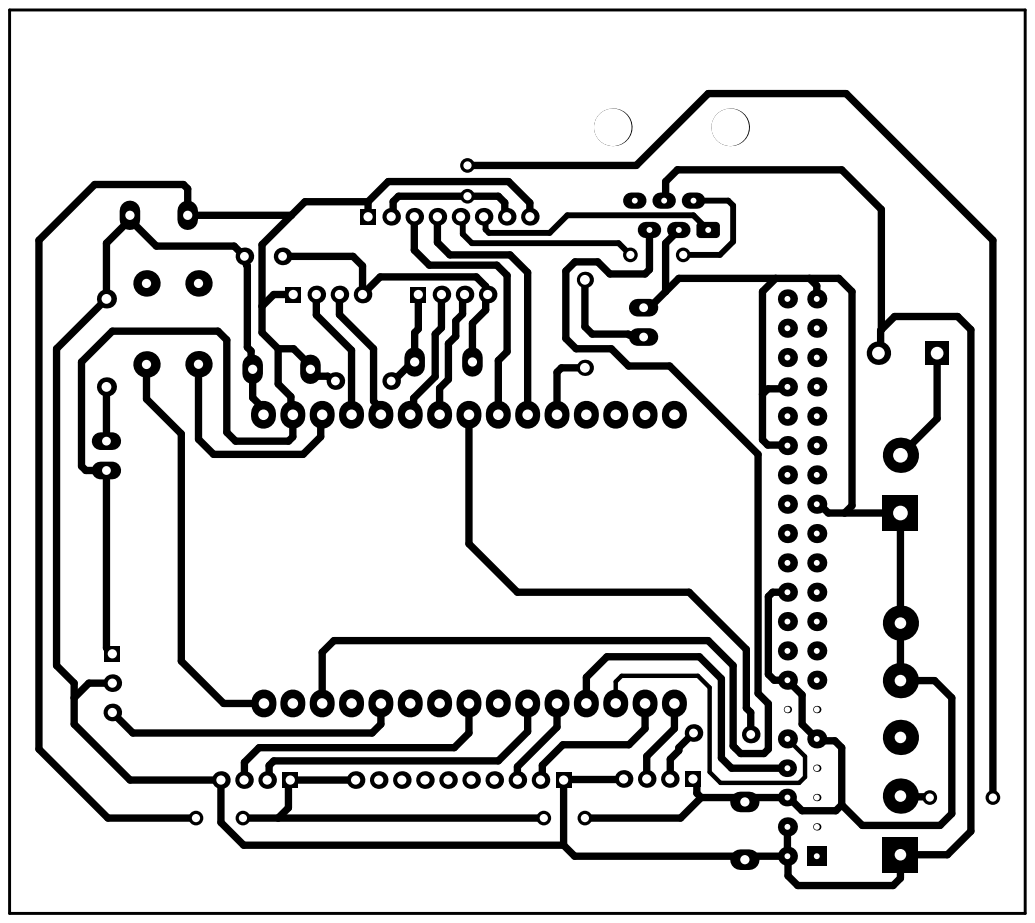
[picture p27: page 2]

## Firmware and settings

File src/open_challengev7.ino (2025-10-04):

#include <Wire.h>
#include <MPU9250_asukiaaa.h>
#include <ESP32Servo.h> // Agregado para controlar servo

MPU9250_asukiaaa mySensor;
Servo servoMotor;       

// Solo variables necesarias para Yaw, gyroZ_raw y gyroZ_f
float yaw = 0.0;
float gyroZ_raw = 0.0;
float gyroZ_f = 0.0;      // gyroZ filtrado
float gyroZ_offset = 0.0; // offset calculado en calibración

// Tiempo
unsigned long prevTime = 0;
float dt = 0.0; // segundos

// Parámetros
const int CAL_SAMPLES = 200;     // lecturas para calibrar gyro Z
const float GYRO_ALPHA = 0.92;   // EMA alpha

//Variables paro de motor
int giroCount = 0;                 // Contador de giros realizados
const int maxGiros = 12;           // Número de giros hasta detener el vehículo
bool vehiculoDetenido = false;     // Bandera para saber si ya se detuvo

unsigned long stopMotorTime = 0;       // momento en que se debe detener el motor
const unsigned long stopDelay = 1000;  // 1 segundo en ms
bool pararMotorPendiente = false;      // indica que se debe parar después de delay

// First corner detection
bool firstCornerDetected = false;
bool firstCornerRight = false; // true if first corner was right, false if left



// ===== Pin del servo =====
const int servoPin = 18;

const int in1 = 32;
const int in2 = 33;

// === Pines ultrasónicos ===
const int trigLeft  = 14;
const int echoLeft  = 27;
const int trigRight = 26;
const int echoRight = 25;

const unsigned long usIntervalMs = 100UL; 
int ultrasonicoizquierda = 0;
int ultrasonicoderecha = 0;

unsigned long lastUsRead = 0; 

// === Banderas para controlar ajustes de yaw ===
bool ajustadoDerecha = false;
bool ajustadoIzquierda = false;

// ===== NUEVAS VARIABLES GLOBALES =====
unsigned long lastYawAdjustTime = 0;        // momento del último ajuste
const unsigned long yawBlockTime = 1000;    // tiempo de bloqueo en ms (1 segundo)


// --- Función para leer distancia ---
int leerDistanciaUltrasonico(int trigPin, int echoPin) {
  digitalWrite(trigPin, LOW);
  delayMicroseconds(2);
  digitalWrite(trigPin, HIGH);
  delayMicroseconds(10);
  digitalWrite(trigPin, LOW);

  unsigned long duracion = pulseIn(echoPin, HIGH, 30000UL);

  if (duracion == 0) {
    return -1; // -1 = sin eco
  }

  float distanciaF = (duracion * 0.0343f) / 2.0f;
  int distancia = (int)round(distanciaF);
  if (distancia < 0) distancia = 0;

  return distancia;
}

void motorAvanzar() {
  digitalWrite(in1, HIGH);
  digitalWrite(in2, LOW);
}

void motorDetener() {
  digitalWrite(in1, LOW);
  digitalWrite(in2, LOW);
  vehiculoDetenido = true;
}


void setup() {
  Serial.begin(115200);
  Wire.begin();

  mySensor.setWire(&Wire);
  mySensor.beginGyro();

  // ===== Inicializar servo =====
  servoMotor.attach(servoPin);
  servoMotor.write(90); // posición inicial

  // ===== Inicializar motor =====
  pinMode(in1, OUTPUT);
  pinMode(in2, OUTPUT);

  // Pines ultrasónicos
  pinMode(trigLeft, OUTPUT);
  pinMode(echoLeft, INPUT);
  pinMode(trigRight, OUTPUT);
  pinMode(echoRight, INPUT);

  delay(100);

  // Calibración simple del gyro Z
  Serial.println("Calibrando gyro Z: mantener sensor quieto...");
  double gz_sum = 0.0;
  for (int i = 0; i < CAL_SAMPLES; i++) {
    mySensor.gyroUpdate();
    gz_sum += mySensor.gyroZ();
    delay(5);
  }
  gyroZ_offset = gz_sum / CAL_SAMPLES;
  Serial.print("Offset gyroZ: "); Serial.println(gyroZ_offset, 6);

  // Espera después de calibración para estabilizar
  delay(2000);

  // Arranca motor después de calibración
  motorAvanzar();

  prevTime = micros();
}

void loop() {
  // dt real
  unsigned long currTime = micros();
  dt = (currTime - prevTime) / 1000000.0;
  if (dt <= 0.0) dt = 0.000001;
  prevTime = currTime;

  // actualizar giroscopio
  mySensor.gyroUpdate();

  // leer gyroZ y quitar offset
  gyroZ_raw = mySensor.gyroZ() - gyroZ_offset; 

  // EMA para suavizar (gyroZ_f)
  static bool first = true;
  if (first) {
    gyroZ_f = gyroZ_raw;
    first = false;
  } else {
    gyroZ_f = GYRO_ALPHA * gyroZ_f + (1.0 - GYRO_ALPHA) * gyroZ_raw;
  }

  // integrar yaw
  yaw += gyroZ_f * dt; 

  // ---- Ajuste de referencia inicial ----
  static bool firstYaw = true;
  if (firstYaw) {
    yaw = 90.0;   
    firstYaw = false;
  }

  // Normalizar yaw [0, 360)
  if (yaw >= 360) yaw -= 360;
  if (yaw < 0) yaw += 360;

  // === Redondear yaw a enteros ===
  int yawInt = round(yaw);

  // ===== Mapeo de yaw a servo =====
  int servoAngle = map(yawInt, 45, 135, 50, 130);
  servoAngle = constrain(servoAngle, 50, 130);
  servoMotor.write(servoAngle);

  // ===== Leer ultrasónicos cada cierto intervalo =====
 // ===== Leer ultrasónicos cada cierto intervalo =====
if (millis() - lastUsRead >= usIntervalMs) {
    lastUsRead = millis();

    // Read sensors
    if (!firstCornerDetected || !firstCornerRight) { // Read left only if first corner is not right
        ultrasonicoizquierda = leerDistanciaUltrasonico(trigLeft, echoLeft);
    }
    if (!firstCornerDetected || firstCornerRight) { // Read right only if first corner is not left
        ultrasonicoderecha   = leerDistanciaUltrasonico(trigRight, echoRight);
    }

    unsigned long now = millis();

    // ===== Lógica de ajuste con bloqueo temporal y contador de giros =====
    if (!vehiculoDetenido && (now - lastYawAdjustTime >= yawBlockTime)) {

        // --- Izquierda ---
        if (!firstCornerDetected || !firstCornerRight) {  // Only if allowed
            if (ultrasonicoizquierda > 150) {
                if (!ajustadoIzquierda) {
                    yaw += 89; 
                    ajustadoIzquierda = true;
                    lastYawAdjustTime = now;
                    giroCount++;
                    Serial.print("\t>>> Ajuste -90° (Izquierda)");

                    // First corner detection
                    if (!firstCornerDetected) {
                        firstCornerDetected = true;
                        firstCornerRight = false; // first was left
                    }

                    // Motor stop logic
                    if (giroCount >= maxGiros && !pararMotorPendiente) {
                        stopMotorTime = now;
                        pararMotorPendiente = true;
                    }
                }
            } else if (ultrasonicoizquierda == -1) {
                Serial.print("\t(Sin eco izquierda)");
            } else {
                ajustadoIzquierda = false; 
            }
        }

        // --- Derecha ---
        if (!firstCornerDetected || firstCornerRight) { // Only if allowed
            if (ultrasonicoderecha > 150) {
                if (!ajustadoDerecha) {
                    yaw -= 89; 
                    ajustadoDerecha = true;
                    lastYawAdjustTime = now;
                    giroCount++;
                    Serial.print("\t>>> Ajuste +90° (Derecha)");

                    // First corner detection
                    if (!firstCornerDetected) {
                        firstCornerDetected = true;
                        firstCornerRight = true; // first was right
                    }

                    // Motor stop logic
                    if (giroCount >= maxGiros && !pararMotorPendiente) {
                        stopMotorTime = now;
                        pararMotorPendiente = true;
                    }
                }
            } else if (ultrasonicoderecha == -1) {
                Serial.print("\t(Sin eco derecha)");
            } else {
                ajustadoDerecha = false; 
            }
        }
    }

    // Motor stop after delay
    if (pararMotorPendiente && (millis() - stopMotorTime >= stopDelay)) {
        motorDetener();
        pararMotorPendiente = false;
        Serial.println(">>> Motor detenido después de 1 segundo");
    }

    Serial.println();
}


  // Imprimir info de IMU
  Serial.print("Yaw: "); Serial.print(yawInt);
}

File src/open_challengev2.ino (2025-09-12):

#include <Wire.h>
#include <ESP32Servo.h>

// ---------- VARIABLES NUEVAS PARA CONTROL DE EXTREMOS ----------
/*
unsigned long tiempoEnExtremo = 0;
bool enExtremo = false;
const unsigned long limiteExtremo = 200; // ms en extremo

unsigned long tiempoEnCentro = 0;
bool enCentro = false;
const unsigned long duracionCentro = 180; // ms en 90°

int ultimoServoAngle = 90; // guarda el último ángulo aplicado
*/

// ---------- PINES ----------
const int trigLeft  = 23;
const int echoLeft  = 25;
const int trigRight = 26;
const int echoRight = 27;



const int servoPin = 18;

const int IN1 = 32; // Motor driver input 1
const int IN2 = 33; // Motor driver input 2

// ---------- PARÁMETROS ----------
const unsigned long usIntervalMs = 100UL; // intervalo de lectura ultras (ms)
const int maxDistance = 80;                // máximo considerado por sensor (cm)
const int diffMax = maxDistance;           // máximo (absoluto) para la diferencia
const int servoCenter = 90;
const int servoLeft   = 45;   // ángulo mínimo
const int servoRight  = 135;  // ángulo máximo

// ---------- VARIABLES ----------
Servo myServo;
unsigned long lastUsRead = 0;

int ultrasonicoizquierda = 0;
int ultrasonicoderecha = 0;
int calculodistancia = 0; // izquierda - derecha

// ---------- PROTOTIPOS ----------
void motorAvanzar();
void motorStop();
void motorReversa();
int leerDistanciaUltrasonico(int trigPin, int echoPin);

// ---------- FUNCIONES MOTOR ----------
void motorAvanzar() {
  digitalWrite(IN1, LOW);
  digitalWrite(IN2, HIGH);
}

void motorStop() {
  digitalWrite(IN1, LOW);
  digitalWrite(IN2, LOW);
}

void motorReversa() {
  digitalWrite(IN1, HIGH);
  digitalWrite(IN2, LOW);
}

// ---------- FUNCION ULTRASONICO ----------
int leerDistanciaUltrasonico(int trigPin, int echoPin) {
  digitalWrite(trigPin, LOW);
  delayMicroseconds(2);
  digitalWrite(trigPin, HIGH);
  delayMicroseconds(10);
  digitalWrite(trigPin, LOW);

  unsigned long duracion = pulseIn(echoPin, HIGH, 30000UL);

  if (duracion == 0) {
    return 0; // sin eco → devolvemos 0
  }

  float distanciaF = (duracion * 0.0343f) / 2.0f;
  int distancia = (int)round(distanciaF);
  if (distancia < 0) distancia = 0;

  return distancia;
}

// ---------- SETUP ----------
void setup() {
  Serial.begin(115200);
  delay(10);

  pinMode(IN1, OUTPUT);
  pinMode(IN2, OUTPUT);
  motorStop();

  pinMode(trigLeft, OUTPUT);
  pinMode(echoLeft, INPUT);
  pinMode(trigRight, OUTPUT);
  pinMode(echoRight, INPUT);
  digitalWrite(trigLeft, LOW);
  digitalWrite(trigRight, LOW);

  myServo.attach(servoPin);
  myServo.write(servoCenter);
  delay(200);

  Serial.println("Setup listo. Empezando lecturas (millis non-blocking).");
}

// ---------- LOOP ----------
void loop() {
  unsigned long now = millis();

  if (now - lastUsRead >= usIntervalMs) {
    lastUsRead = now;

    ultrasonicoizquierda = leerDistanciaUltrasonico(trigLeft, echoLeft);
    ultrasonicoderecha  = leerDistanciaUltrasonico(trigRight, echoRight);

    calculodistancia = ultrasonicoizquierda - ultrasonicoderecha;

    if (calculodistancia > diffMax) calculodistancia = diffMax;
    if (calculodistancia < -diffMax) calculodistancia = -diffMax;

    int servoAngle = map(calculodistancia, -diffMax, diffMax, servoLeft, servoRight);

    // ---- CONTROL DE TIEMPO EN EXTREMOS ----
    /*
    if (servoAngle == servoLeft || servoAngle == servoRight) {
      if (!enExtremo) {
        tiempoEnExtremo = now;
        enExtremo = true;
      } else {
        if (now - tiempoEnExtremo >= limiteExtremo) {
          servoAngle = servoCenter; // forzar regreso a 90°
          enExtremo = false;
          tiempoEnCentro = now; // empezar contador de 200 ms en 90°
          enCentro = true;
        }
      }
    } else {
      enExtremo = false;
    }

    // ---- CONTROL DE DURACION EN CENTRO ----
    if (enCentro) {
      if (now - tiempoEnCentro < duracionCentro) {
        servoAngle = servoCenter; // mantener 90°
      } else {
        enCentro = false; // se acabó el tiempo en 90°, seguir normal
      }
    }

    ultimoServoAngle = servoAngle;
    */
    

    myServo.write(servoAngle);

    motorAvanzar();

    Serial.print("Izq: "); Serial.print(ultrasonicoizquierda);
    Serial.print(" cm | Der: "); Serial.print(ultrasonicoderecha);
    Serial.print(" cm | Diff: "); Serial.print(calculodistancia);
    Serial.print(" -> Servo: "); Serial.println(servoAngle);
  }
}

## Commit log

2025-09-12 Create Second code
    This code includes the use of two lateral ultrasonic sensors for the open challenge
2025-09-21 Renombradas carpetas según nueva estructura profesional
    [firsyAssembly.stl]
2025-10-04 Add schematic PDF and preview image
2025-11-05 Create chassis
2025-11-05 update models
    [backSupport.step, backSupportSTL.stl, mainBase.step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]
